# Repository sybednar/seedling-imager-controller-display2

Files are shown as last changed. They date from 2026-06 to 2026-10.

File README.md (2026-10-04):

# Seedling Imager Controller

## Overview
Inspired by the SPIRO (Smart Plate Imaging Robot; Ohlsson et al The Plant Journal doi: 10.1111/tpj.16587) project, the **Seedling Imager** is a Raspberry Pi 5-based imaging system designed to monitor Arabidopsis seedling growth using a 6-position hexagonal carousel. It provides automated imaging, LED control, and experiment scheduling through a touch-friendly GUI.

# Seedling Imager Controller — Universal

**v1.3.0** · Raspberry Pi 5 · PySide6 · picamera2 (or Arducam USB3) · GT2 belt carousel

A touchscreen controller for automated timelapse imaging of seedling plates using near-infrared (940 nm) transmission and front illumination. A single codebase runs on both supported display configurations without any code changes.

Repository: **https://github.com/sybednar/seedling-imager-controller-display2**

---

## Supported Hardware

| Component | System 1 (original) | System 2 |
|---|---|---|
| Display | Original 800×480 DSI touchscreen | Raspberry Pi Touch Display 2 (1280×720) |
| Scale factor `s` | 1.0 | 1.6 |
| Camera | Raspberry Pi HQ Camera | Raspberry Pi HQ Camera |
| Compute | Raspberry Pi 5 | Raspberry Pi 5 |
| Motor | Stepper + GT2 belt carousel | Stepper + GT2 belt carousel |
| Illumination | Dual 940 nm IR LEDs (front + rear) | Dual 940 nm IR LEDs (front + rear) |
| Optical sensor | Photointerrupter (hall + flag) | Photointerrupter (hall + flag) |
| Power (Pi 5) | SZZCNOX 5V/5A PD step-down module | SZZCNOX 5V/5A PD step-down module |

GUI layout, font sizes, button heights, and dialog dimensions all auto-scale via `s = screen_width / 800`. No separate display-specific files are needed.

> **Power supply note:** both systems use the same SZZCNOX 5V/5A USB-PD step-down board. A different-brand step-down module was tried on System 2 during a hardware upgrade and measured **5.42 V** on the Pi 5's 5V rail (GPIO pins 2/4) instead of 5.0 V — that ~0.2 V overvoltage is the confirmed cause of an intermittent shutdown/reboot hang (`plymouth-poweroff`/`plymouth-reboot` stuck for 1–2 minutes, or indefinitely). Swapping back to the SZZCNOX module resolved it completely. **Measure your 5V rail voltage before troubleshooting any shutdown/reboot instability in software** — it will look exactly like an OS or application bug otherwise. See Troubleshooting below.

---

## Key Features (v1.1.0)

### GUI & Display
- Auto-scaling dark theme UI: `s = screen_width / 800` (1.0 at 800 px, 1.6 at 1280 px)
- Fullscreen kiosk mode; all widget dimensions computed as `int(X * s)`
- `dark_style(s)` parameterized stylesheet — font, padding, and border-radius all scale

### Imaging
- Dual 940 nm IR illumination modes: **Front IR**, **Rear IR (transmission)**, **Combined**
- Per-mode camera presets stored in `camera_settings.json` (`FrontIR_*` / `RearIR_*` keys)
- Manual focus locked via `set_manual_focus()` at camera start (measured per unit — see Calibration Notes)
  - PDAF non-functional through 940 nm bandpass filter; manual focus required
- 16-bit grayscale TIFF output (`tifffile`; OpenCV fallback for non-TIFF formats)
- AE stability gate: polls `AnalogueGain` until < 5% relative change over 5 consecutive reads before pinning exposure
- `settling_started` signal emitted **after** AE is pinned and 0.20 s settle — GUI preview snapshot matches saved image exposure
- Live-view IR boost (mode-specific gain/exposure floor) enabled during preview, disabled before capture

### Motor / Carousel
- GT2 belt drive with dynamic bracket homing:
  1. CCW to LOW (leading edge of optical flag)
  2. CCW to HIGH (past leading edge)
  3. CW to LOW (re-validate leading edge)
  4. CW + `mid` µsteps to geometric center
- **Microstepping: 1/32** (BTT TMC2209: MS2=GND, MS1=VCC_IO). `steps_per_60_deg = 3200`.
  - This replaces the earlier 1/8-microstepping configuration (`steps_per_60_deg = 800`). 1/32 microstepping gives substantially finer positioning resolution and improved plate-to-plate registration — see Version History below.
  - **If you are upgrading an existing unit from a lower microstepping setting, delete `motion_cal.json` before the first run** — the saved calibration values do not scale automatically.
- Optical window `W` measured physically each homing run by counting µsteps CW across the sensor aperture (expected W ≈ 192 µsteps at 1/32 microstepping for the 5 mm stripe)
  - W is **not** a configurable parameter — it is measured live every homing cycle
- `CENTER_BACKOFF_FRAC = 0.0`: places carousel at exact geometric center regardless of W
  - Formula: `mid = max(1, int(round(W / 2.0 * (1.0 - CENTER_BACKOFF_FRAC))))`
  - Increase slightly (e.g. 0.05) only if consistent leading-edge drift is observed
- Log output includes `frac=` and `W=` on every homing for traceability

### Camera Backend (Picamera2 / Arducam USB3)
- Selectable in Camera Config → General tab: **Raspberry Pi Camera Module 3 (Picamera2)** [default] or **Arducam 20MP AR2020 Mono USB3**
- Persisted as `CameraBackend` in `camera_settings.json`; **switching requires an application restart** — the backend is fixed for the lifetime of the running process (`camera.py` only imports the selected backend module, since each one claims its physical camera device at import time)
- `camera.py` is a thin dispatcher: every other module calls `camera.get_frame()`, `camera.save_image()`, etc. unchanged regardless of which backend is active
- Arducam backend validated on physical hardware (Sept 2026): full-resolution reopen/discard/retry sequence confirmed reliable across extended multi-cycle experiments, including a `mock_capture()` path that exercises the same reopen sequence for unselected plates so every plate position gets a fresh, reliable on-screen preview whether or not it is actually captured that cycle. Before relying on it for a new unit:
  1. `sudo apt install v4l-utils` (already included in `install_dependencies.sh`)
  2. Connect the camera, then run `python3 -c "import camera_arducam_usb3 as c; c.print_diagnostics()"` — reports the detected `/dev/videoN` device, every resolution/format the driver advertises, and every V4L2 control it exposes
  3. Compare against the assumptions documented at the top of `camera_arducam_usb3.py` (control names, resolutions, mode-switch timing) and adjust the constants there if they don't match
- The Arducam is a **fixed physical manual-focus lens** (twist the M12 ring by hand) — there is no AF motor, so `set_manual_focus()`/AF-related calls are safe no-ops on this backend; the Focus tab in Camera Config has no effect when Arducam is selected
- UVC cameras generally stream one resolution at a time, unlike Picamera2's simultaneous main+lores streams — the Arducam backend runs live preview at a lower resolution continuously and briefly reconfigures to full resolution for each saved image (or each mock capture), so expect a short pause per cycle that the Picamera2 backend does not have

### Germination / Photomorphogenesis LEDs
- Independent on/off toggle buttons for **Blue (450 nm)**, **Red (660 nm)**, and **FarRed (730 nm)** — driven low-side via 3× IRLZ44N MOSFETs on the auxiliary MOSFET board
- Not coupled to the IR imaging illumination cycle — hold any combination on (e.g. Red+FarRed for a red:far-red ratio treatment) while IR imaging continues independently
- State is not persisted between sessions — all three channels default OFF at startup

### Camera Config Dialog
- Tabbed interface: General settings (incl. Camera Backend selector) + Focus + IR-specific presets
- "White LED Front" toggle button (GPIO23, persistent button row next to Apply/Close, not inside the Focus tab so it stays usable for either camera backend) — illuminates a Siemens star target during manual focus calibration; automatically turns off when the dialog closes (Close button, window X, or Escape key)
- Non-blocking "Read Current Position from Camera" button — `_FocusReader(QThread)` worker prevents GUI freeze when Live View is off
- Button disabled during read, re-enabled on completion or error

### Experiment Setup
- Configurable plate selection, frequency (default 30 min), duration, illumination mode
- Disk usage estimate uses `IMAGES_ROOT = Path("/home/sybednar/Seedling_Imager/images")` — **this path is hardcoded in `experiment_setup.py`.** If you use a different Linux username or folder layout, you must edit this line (see Setup, Step 0).
- Storage label colour: green (sufficient free space) / red (insufficient)

### File Manager
- Thumbnail grid with per-image metadata overlay
- Scaled thumbnail size: `QSize(int(100 * s), int(100 * s))`

---

## Module Structure

```
Seedling_Imager/                          # top-level project folder (NOT the git repo)
├── images/                               # timelapse output — IMAGES_ROOT (hardcoded path)
└── seedling_imager_controller/           # git clone of this repository
    ├── venv/                             # Python virtual environment (created locally, not in git)
    ├── main.py                           # Entry point; launches QApplication fullscreen
    ├── gui.py                            # Main window; computes s = screen_width / 800
    ├── styles.py                         # dark_style(s) — parameterized stylesheet
    ├── camera.py                         # Camera BACKEND DISPATCHER — selects picamera2 vs arducam_usb3
    ├── camera_picamera2.py               # Picamera2 backend; manual focus; TIFF save; AE gate
    ├── camera_arducam_usb3.py            # Arducam 20MP AR2020 mono USB3 backend (OpenCV/V4L2)
    ├── camera_config.py                  # Camera Config dialog; Camera Backend selector; _FocusReader QThread
    ├── motor_control.py                  # Stepper driver; dynamic bracket homing; 1/32 microstepping
    ├── experiment_runner.py              # Timelapse loop; AE settle; settling_started signal
    ├── experiment_setup.py               # Setup dialog; plate/frequency/mode/disk usage
    ├── file_manager.py                   # File browser with thumbnail grid
    ├── registration.py                   # Per-plate phase cross-correlation registration analysis
    ├── jog.py                            # Manual motor jog utility for bench testing
    ├── camera_settings.json              # Persisted camera presets (FrontIR_*, RearIR_* keys)
    ├── motion_cal.json                   # Persisted motor calibration (auto-created on first homing)
    ├── requirements.txt                  # pip dependencies (installed inside venv)
    ├── install_dependencies.sh           # One-shot apt + venv + pip installer
    ├── start_seedling_imager.sh          # Launch wrapper used by both autostart methods below
    ├── restart_seedling_imager.sh        # Manual stop/relaunch (used by desktop icon)
    ├── seedling-imager-autostart.desktop # XDG autostart template — RECOMMENDED (see Setup Step 8)
    ├── seedling-imager.service           # systemd --user service template — optional/alternative (see Setup Step 8)
    ├── Seedling_Imager.desktop           # Desktop icon template — start/restart the controller (see Setup Step 9)
    ├── git_update.sh                     # Convenience script for commit + tag + push
    ├── hardware/                         # CAD (STEP), KiCad boards, BOM, render, hardware licence — see hardware/README.md
    ├── logs/                             # Experiment run logs
    └── README.md
```

---

## GPIO Pin Map (as of v1.2.0)

All pins below are on the auxiliary MOSFET board or the motor driver, addressed via `gpiod` against `/dev/gpiochip0`.

| GPIO | Function | Module |
|---|---|---|
| 12 | Germination LED — Blue 450 nm | `gui.py` |
| 13 | Germination LED — Red 660 nm | `gui.py` |
| 16 | Motor DIR | `motor_control.py` |
| 17 | Front IR imaging panel (reflectance) | `gui.py` |
| 19 | Germination LED — FarRed 730 nm | `gui.py` |
| 20 | Motor STEP | `motor_control.py` |
| 21 | Motor driver EN | `motor_control.py` |
| 22 | Optical sensor (reflective stripe) | `motor_control.py` |
| 23 | Front panel White LED strip (Siemens star illumination during manual focus calibration) | `camera_config.py` |
| 24 | Green front illumination | `gui.py` |
| 26 | Hall sensor (motor pre-index) | `motor_control.py` |
| 27 | Rear IR imaging panel (transmission) | `gui.py` |

**v1.2.0 pin reshuffle:** `OPTICAL_PIN` moved 19→22 and the front/rear IR imaging panels moved 13→17 and 12→27, freeing GPIO12/13/19 for the three germination LED channels above. If you're carrying forward calibration or wiring notes from before v1.2.0, update them against this table, not the older pin numbers referenced in earlier Version History entries.

---

## Dependencies

Installed as **apt system packages** (compiled against Raspberry Pi OS's libcamera/Qt6/GPU libraries — do not pip-install these):
```
python3-picamera2
python3-pyside6.*    (no single "python3-pyside6" metapackage on current Raspberry Pi OS/Debian
                       Trixie — PySide6 is split per Qt module; the wildcard installs all of them:
                       sudo apt install 'python3-pyside6.*')
python3-numpy
python3-opencv      (cv2)
v4l-utils           (provides v4l2-ctl — only needed if using the Arducam USB3 camera backend)
libxcb-cursor0      (required by Qt >= 6.5's xcb platform plugin; usually already present, but
                     confirmed missing on at least one fresh Raspberry Pi OS Trixie image — see
                     Troubleshooting)
```

Installed as **pip packages inside the project virtual environment** (see `requirements.txt`):
```
tifffile   (16-bit TIFF read/write)
gpiod>=2.0 (stepper/LED GPIO — modern gpiod.line API; see https://pypi.org/project/gpiod/)
```

> **Note on GPIO library:** this project uses `gpiod` (the modern libgpiod v2.x Python bindings), **not** `RPi.GPIO` and **not** `gpiozero`. Both are absent from the codebase. `gpiod` is installed via pip (not apt) because the apt-packaged `python3-libgpiod` on current Raspberry Pi OS releases may ship an older 1.x API incompatible with `motor_control.py`'s `gpiod.line.Direction/Value/Bias` usage.

The `install_dependencies.sh` script (see Setup below) installs and verifies all of the above in one step.

---

## Setup — New Raspberry Pi 5 (Step by Step for Novices)

These instructions assume you have already flashed Raspberry Pi OS (Bookworm or Trixie) onto the NVMe/SD card, booted to the desktop, confirmed **Desktop Autologin** is enabled for your user (`sudo raspi-config` → System Options → Boot / Autologin → Desktop Autologin), and connected to Wi-Fi/Ethernet. All commands are run in a terminal on the Raspberry Pi itself (or over SSH — except where noted in Step 8/9, where a few things must be checked from a terminal running *inside* the desktop session itself).

### Step 0 — Confirm your Linux username

The code hardcodes the path `/home/sybednar/Seedling_Imager/...` in two places (`experiment_setup.py`'s `IMAGES_ROOT`, and the autostart scripts). Open a terminal and run:

```bash
whoami
```

- If it prints `sybednar`, continue to Step 1 as written.
- If it prints anything else, either (a) create a `sybednar` user on this Pi, or (b) do a project-wide find-and-replace of `/home/sybednar/` with `/home/<your-username>/` in `experiment_setup.py`, `start_seedling_imager.sh`, `restart_seedling_imager.sh`, `seedling-imager.service`, and `seedling-imager-autostart.desktop` before proceeding.

### Step 1 — Create the project folder

```bash
mkdir -p /home/sybednar/Seedling_Imager/images
cd /home/sybednar/Seedling_Imager
```

### Step 2 — Clone the repository

```bash
git clone https://github.com/sybednar/seedling-imager-controller-display2.git seedling_imager_controller
cd seedling_imager_controller
```

(HTTPS clone requires no GitHub account or SSH key setup — fine for read-only cloning of this public repo. If you need the Arducam USB3 branch specifically, add `-b arducam-integration` to the clone command.)

### Step 3 — Install dependencies (one command)

```bash
chmod +x install_dependencies.sh
./install_dependencies.sh
```

This installs the apt system packages, creates `venv/` with `--system-site-packages`, installs `requirements.txt` into it, and prints a verification check for every dependency (picamera2, PySide6, opencv, numpy, tifffile, gpiod). **Do not continue to Step 4 until this script finishes with no errors.**

### Step 4 — Make the launch/restart scripts executable

```bash
chmod +x start_seedling_imager.sh restart_seedling_imager.sh
```

### Step 5 — First manual run (before enabling autostart)

Always test manually first — it's much easier to read errors in a live terminal than in a log file. Run this from a terminal opened **on the Pi's own desktop** (not a bare SSH session), since the app needs the desktop's live display/session environment:

```bash
source venv/bin/activate
python3 main.py
```

The app should open fullscreen. Use Alt+F4 (or the on-screen Exit control, if present) to close it and return to the terminal. If it fails to start, see Troubleshooting below before continuing.

### Step 6 — Calibrate manual focus for this camera unit

Manual focus is **per-camera-unit** and must be re-measured on every new Pi/camera pairing — do not reuse another unit's value. Follow the steps in the repository's `Setting manual camera focus instructions` file, then update the `ManualFocusPosition` value(s) in `camera_settings.json`.

### Step 7 — Confirm the motor calibration file is fresh

If this SSD/OS image was ever used with a different microstepping setting or a different physical unit, delete the stale calibration before the first homing run:

```bash
rm -f /home/sybednar/Seedling_Imager/seedling_imager_controller/motion_cal.json
```

It will be recreated automatically the first time `home()` runs successfully from the GUI.

### Step 8 — Enable autostart (XDG autostart, recommended)

Two mechanisms exist for autostarting the controller GUI when the desktop session starts: a **systemd `--user` service** and an **XDG autostart `.desktop` entry**. Real-world testing across two different Pi 5 units (and, on one of them, two different OS images) consistently found the systemd method **unreliable for this application**: it works fine when started by hand in an already-running session (`systemctl --user enable --now ...`), but on a genuine cold `sudo reboot` it either fails with a Qt platform-plugin error or exits silently a few seconds after launch, with no window ever appearing. The confirmed root cause is that the systemd user manager on these Pi 5 / labwc images does not reliably import `XAUTHORITY`/`WLR_XWAYLAND` into its environment the way an interactive desktop session does — `DISPLAY` and `WAYLAND_DISPLAY` are present, but the xcb/XWayland platform plugin still can't authenticate without those two extra variables. `start_seedling_imager.sh` already sets explicit fallback defaults for both (see the script), which helps but has not made systemd fully reliable across every image tested. The **XDG autostart** method sidesteps the problem entirely, since the compositor launches it directly inside the already-fully-initialized session — it has been 100% reliable across every reboot/shutdown test performed. **Use it as the primary method:**

```bash
mkdir -p ~/.config/autostart
cp seedling-imager-autostart.desktop ~/.config/autostart/seedling-imager.desktop
```

**Reboot the Pi with `sudo reboot` (a real reboot — not `systemctl --user start`) and confirm the controller launches automatically to the fullscreen GUI.** Also test a full `sudo shutdown now` to confirm the Pi actually powers off cleanly. Testing only with a live-session start can look successful and still fail on a real cold boot — always validate with an actual reboot and an actual shutdown before considering autostart done.

If the GUI doesn't appear, check the log first:

```bash
tail -80 /home/sybednar/Seedling_Imager/seedling_imager_controller/autostart.log
```

<details>
<summary>Optional: systemd <code>--user</code> service (alternative method — click to expand)</summary>

If you'd prefer process supervision (automatic restart on crash) and are willing to validate it carefully, the systemd unit is still provided:

```bash
mkdir -p ~/.config/systemd/user
cp seedling-imager.service ~/.config/systemd/user/
systemctl --user daemon-reload
systemctl --user enable --now seedling-imager.service
```

Check it's running:

```bash
systemctl --user status seedling-imager.service --no-pager -l
```

**Do not stop here** — this only confirms it works when started inside your current live session, which is exactly the false-positive result seen on both test units before a real reboot exposed the failure. Reboot and re-check status/log before trusting it:

```bash
sudo reboot
# after it comes back up:
systemctl --user status seedling-imager.service --no-pager -l
tail -80 /home/sybednar/Seedling_Imager/seedling_imager_controller/autostart.log
```

If it fails (Qt platform-plugin error, or the log shows the script exiting cleanly within a few seconds of launch with no other error), fall back to the XDG method above:

```bash
systemctl --user disable --now seedling-imager.service
mkdir -p ~/.config/autostart
cp seedling-imager-autostart.desktop ~/.config/autostart/seedling-imager.desktop
sudo reboot
```

</details>

### Step 9 — Add the "Seedling Imager" desktop icon

This lets you start (or stop-and-relaunch) the controller from the touchscreen — e.g. after using "Exit to Desktop" to review files — without rebooting the Pi.

```bash
cp Seedling_Imager.desktop ~/Desktop/
chmod +x ~/Desktop/Seedling_Imager.desktop
```

**Two one-time desktop settings, or the icon won't work smoothly:**

1. On first double-click, the file manager may show an "Untrusted application launcher" warning — right-click the icon and choose **Allow Launching** (or **Trust**), then it will run normally from then on.
2. By default, clicking an executable `.desktop`/script icon pops up an "Execute / Execute in Terminal / Display / Cancel" dialog every time instead of just running it. To disable this: open the **File Manager**, go to **Edit → Preferences** (or right-click the desktop → **Desktop Preferences**, depending on OS version), find the **General** tab, and check **"Don't ask options on launch executable file."** Without this, every click on the icon interrupts the user with an extra dialog.

The icon uses `seedlings.png` (already in this repo) and calls `restart_seedling_imager.sh`, which kills any already-running instance of the GUI and relaunches `start_seedling_imager.sh` fresh — safe to click whether or not the controller is currently running.

### Step 10 — Run a short registration test

Run a short multi-cycle experiment (a few plates, a few cycles) and inspect results with `registration.py` to confirm the 1/32-microstepping `motor_control.py` gives the same registration improvement seen on System 1 before starting a long unattended run.

---

## Troubleshooting

| Symptom | Likely cause / fix |
|---|---|
| `pip install` fails with "externally-managed-environment" | You're not inside the venv, or the venv was created without `--system-site-packages`. Re-run `source venv/bin/activate` first, or rebuild the venv per Step 3. |
| `ModuleNotFoundError: No module named 'picamera2'` inside the venv | The venv wasn't created with `--system-site-packages`, or the apt package `python3-picamera2` isn't installed. Rebuild: `rm -rf venv && python3 -m venv --system-site-packages venv`, then re-run `install_dependencies.sh`. |
| `ImportError: cannot import name 'Direction' from 'gpiod.line'` | An old `gpiod` (1.x) is shadowing the pip-installed 2.x version. Confirm with `venv/bin/pip show gpiod` (should be ≥2.0) and re-run `venv/bin/pip install --upgrade gpiod`. |
| `qt.qpa.plugin: Could not load the Qt platform plugin "xcb" ... xcb-cursor0 or libxcb-cursor0 is needed` | Missing system library required by Qt ≥ 6.5. Fix: `sudo apt-get install -y libxcb-cursor0`. Seen on a fresh Raspberry Pi OS Trixie image where it wasn't pulled in automatically. |
| `qt.qpa.xcb: could not connect to display` when testing manually | You're running the command over plain SSH (no `DISPLAY`), not in a terminal inside the desktop session. Either open a terminal locally on the Pi's touchscreen, or (for a quick manual check only) `export DISPLAY=:0` in the SSH shell first. |
| GUI never appears at boot, but manual `python3 main.py` (run inside the desktop session) works fine | This is the systemd `XAUTHORITY`/`WLR_XWAYLAND` gap described in Setup Step 8. Switch to the XDG autostart method — don't spend time tuning `QT_QPA_PLATFORM` or startup delay first, since neither addresses the actual cause. |
| systemd service shows `enabled`, `autostart.log` shows the script reach `Seedling Imager launch end` a few seconds after launch, but no window ever appeared | The app started and exited cleanly on its own under systemd — a different, not-fully-understood failure mode from the Qt platform-plugin error above, also resolved by switching to XDG autostart. Confirmed independent of camera backend and hardware revision. |
| systemd service works when started by hand (`enable --now`) but not after a real `sudo reboot` | Expected — see Setup Step 8. Validate autostart only with a genuine reboot, never with a live-session start. |
| `sudo shutdown`/`sudo reboot` hangs for 1–2 minutes (or indefinitely) at a `plymouth-poweroff`/`plymouth-reboot` message | Check your Pi 5's 5V rail voltage (GPIO pins 2/4) before assuming it's a software issue — a step-down power module running even slightly over 5.0 V (5.4 V confirmed to cause this) can produce exactly this symptom. See the Power Supply note near the top of this README. Also run `sudo rpi-eeprom-update` and apply any pending bootloader update (`sudo rpi-eeprom-update -a && sudo reboot`) as a secondary check, especially on units with an NVMe HAT. A momentary pushbutton wired to the J2 GPIO shutdown pins will reliably force a clean power-down while you diagnose this. |
| Clicking the desktop icon pops up an Execute/Terminal/Cancel dialog every time | See Setup Step 9 — enable "Don't ask options on launch executable file" in the File Manager's preferences. |
| Homing/centering seems off after this update | Delete `motion_cal.json` and re-home — old calibration values from a different microstepping setting do not carry over (see Motor / Carousel notes above). |

---

## Migrating an Existing Unit to This Layout

If a unit's folder/autostart layout predates this document, bringing it in line is usually a small job, not a rebuild:

1. **Confirm the folder structure first before assuming anything needs to move.** Check `ls -la /home/<user>/Seedling_Imager/` and `ls -la /home/<user>/Seedling_Imager/seedling_imager_controller/venv/bin/python3` — many units already have the correct layout (repo cloned into `Seedling_Imager/seedling_imager_controller/`, venv nested inside it) even if that wasn't true at some earlier point in the unit's history. Don't move files that are already in the right place.
2. **The autostart mechanism is the part most likely to need changing.** If the unit currently relies on the systemd `--user` service, convert it to the XDG autostart method per Setup Step 8 — do this even if the systemd version currently "seems to work," since a live-session start can pass while a real cold reboot fails (see Troubleshooting). Validate with an actual `sudo reboot` and `sudo shutdown`, not just `systemctl --user enable --now`.
3. Update the desktop icon to the current `Seedling_Imager.desktop` template and confirm the File Manager preference from Setup Step 9 is set.
4. Back up (rename, don't delete) any old/stale project folders before removing them, and only delete the backups once the converted unit has been confirmed working across a real reboot and shutdown.
5. **Do not touch a unit while it is running an experiment.** Do this migration between experimental runs.

---

## Calibration Notes

### Manual Focus
- Manual focus is per-camera-unit. Measure and set `ManualFocusPosition` in `camera_settings.json` for each new system — do not copy another system's value.
- PDAF is non-functional through the 940 nm bandpass filter on both systems.

### Optical Window W
W is measured automatically on every homing cycle — no manual configuration needed. Expect W ≈ 192 µsteps at 1/32 microstepping for the 5 mm stripe.

### CENTER_BACKOFF_FRAC
At the top of `motor_control.py`. Default `0.0` places the carousel at exact geometric window center. Only increase if consistent leading-edge drift is observed in registration analysis.

---

## Hardware Design Files

The complete open-source hardware design is in [`hardware/`](hardware/README.md): the full assembly and individual parts in STEP format, KiCad 10 schematics and PCB layouts for the controller boards and hall sensor board, and a bill of materials (`hardware/CAD Files/bill_of_materials.md`). The native Fusion archive (`.f3z`) and full-assembly STEP are too large for the repository and are attached to the [latest GitHub Release](https://github.com/sybednar/seedling-imager-controller-display2/releases/latest). Hardware files are licensed under CERN-OHL-S v2; the software is MIT.

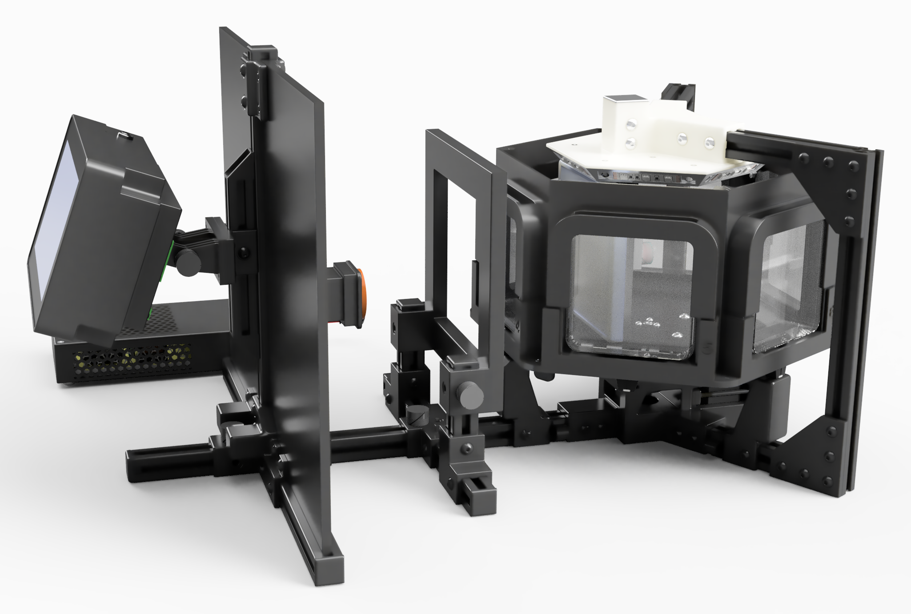
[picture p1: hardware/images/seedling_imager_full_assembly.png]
Seedling imager full assembly render


---

## Version History

### v1.3.2 — 2026-10-04 — Hardware documentation and naming corrections

- Renamed the IR filter holder component to "850 nm long-pass filter holder" in the CAD (Fusion archive and all STEP files)
- Clarified that the camera housing, filter holder and rail corner bracket are included in the Picamera mount STEP; updated root README, CHANGELOG and citation
- Software unchanged from v1.3.0

### v1.3.1 — 2026-10-04 — Complete hardware design files

- Added the complete hardware design (`hardware/`): full-assembly STEP (zipped) and individual part STEP files by subsystem, KiCad 10 files for controller board 1, board 2 and the hall sensor board, bill of materials, assembly render, and CERN-OHL-S v2 licence/notice
- Fusion archive (`.f3z`) and full-assembly STEP attached to the GitHub Release (files exceed GitHub's 100 MB repository limit)
- Added root `LICENSE` (MIT) for the software
- Software unchanged from v1.3.0

### v1.3.0 — 2026-09-27 — Arducam reliability fixes, White LED Front control, Picamera2 for production

**Reliability fixes**
- Fixed `focus_tune.py` sharpness score: removed per-frame min/max contrast normalization that was causing the reported score to rise with *increasing* defocus instead of decreasing
- Fixed Arducam USB3 single-capture failure (root-caused via `dmesg`: `uvcvideo: Failed to resubmit video URB`, a genuine kernel-level USB/firmware wedge triggered by rapid full-res/preview mode switching) — added a settle delay before reopening the device plus self-healing device re-detection (`_find_device(force_refresh=True)`)

**New hardware control**
- Added a "White LED Front" toggle button (GPIO23) to the Camera Config dialog, placed in the persistent button row so it stays usable regardless of active tab or selected backend. Illuminates a Siemens star target for manual focus calibration on either camera; auto-shuts-off via the dialog's `finished` signal so it turns off no matter how the dialog is closed
- Corrected GPIO Pin Map: GPIO23 and GPIO24 were previously documented as "reserved, not yet implemented" — GPIO24 was already driving the Green front illumination LED (`gui.py`), and GPIO23 now drives the White LED Front strip above, both via the AO4805 MOSFET auxiliary board

**Hardware/production decision**
- Head-to-head image-quality comparison on both systems (focus, depth of field, sharpness) showed Picamera2/Camera Module 3 substantially outperforming the Arducam 20MP AR2020 Mono + AICO M12 lens combination for real seedling-plate imaging, after root-causing the Arducam's low sharpness ceiling to a Minimum-Object-Distance violation (measured working distance below the lens's MOD). Both systems switched to Picamera2 for production experiments; the Arducam lens/working-distance problem is tabled for future revisit — the backend and its fixes above remain in the codebase and selectable via Camera Config

**Repo maintenance**
- Consolidated system 1 onto `origin/main`, resolving stale branch/merge-conflict history
- Fixed GitHub default branch (was pointing to the archived `archive-pre-arducam-2026-04` branch instead of `main`); deleted stale `arducam-integration` and `archive-pre-arducam-2026-04` branches and the leftover local `main-old-stale`

### v1.2.1 — 2026-09 — Autostart reliability fix + setup documentation overhaul

**Autostart**
- Root-caused systemd `--user` autostart unreliability to `XAUTHORITY`/`WLR_XWAYLAND` not being reliably imported into the systemd user manager's environment on Pi 5/labwc images, even though `DISPLAY`/`WAYLAND_DISPLAY` are present. `start_seedling_imager.sh` now sets explicit fallback defaults for both.
- XDG autostart (`~/.config/autostart/`) promoted to the **recommended** primary method after passing repeated real cold-reboot and full-shutdown testing on two separate physical units; systemd retained as a documented, secondary/optional method.
- Desktop icon renamed/consolidated to a single `Seedling_Imager.desktop` template (start-or-restart), replacing the earlier restart-only icon naming.

**Hardware**
- Documented a confirmed root cause for intermittent `plymouth-poweroff`/`plymouth-reboot` shutdown hangs: a non-matching 5V step-down power module running at 5.42 V instead of 5.0 V. Resolved by standardizing on the SZZCNOX 5V/5A module on both systems.
- Added `sudo rpi-eeprom-update` as a secondary shutdown-instability check, particularly for units with an NVMe HAT.

**Camera**
- Arducam USB3 backend validated against physical hardware across extended multi-cycle runs; added `mock_capture()` so every plate position gets a fresh, reliable on-screen preview regardless of whether that plate is actually captured that cycle.

**Dependencies**
- Added `libxcb-cursor0` as a documented apt dependency (Qt ≥ 6.5 requirement, found missing on a fresh Raspberry Pi OS Trixie image).

### v1.2.0 — 2026-08 — Selectable camera backend, germination LEDs, GPIO reshuffle

**Camera**
- `camera.py` split into a backend dispatcher plus two implementations: `camera_picamera2.py` (existing Picamera2/libcamera code, behavior unchanged) and new `camera_arducam_usb3.py` (OpenCV/V4L2 backend for the Arducam 20MP AR2020 monochrome USB3 camera)
- Backend selectable in Camera Config → General (`CameraBackend` in `camera_settings.json`); requires an app restart to take effect

**Hardware / GPIO**
- Added a 3-channel germination/photomorphogenesis LED strip (Blue 450 nm, Red 660 nm, FarRed 730 nm) with independent GUI on/off toggles, driven low-side via IRLZ44N MOSFETs on a new auxiliary MOSFET board
- Reshuffled GPIO pins to make room: `motor_control.py`'s `OPTICAL_PIN` moved 19→22; `gui.py`'s front/rear IR imaging panel pins moved 13→17 and 12→27. See the GPIO Pin Map above for the full current assignment, including GPIO23/24 reserved for a planned rear-IR940 PWM intensity control (AO4805 mosfet, not yet implemented in software)

**Dependencies**
- Added `v4l-utils` (apt) for the Arducam backend's `v4l2-ctl`-based exposure/gain control

### v1.1.0 — 2026-07 — 1/32 microstepping + documentation overhaul

**Motor**
- `motor_control.py` updated from 1/8 to 1/32 microstepping (`steps_per_60_deg`: 800 → 3200), same single-optical-sensor + 6-stripe dynamic-bracket strategy. Finer step resolution further improves plate-to-plate registration.
- Cleaned a leftover dead-code block in `_debounced_read()`.

**Documentation**
- Corrected GPIO dependency: `RPi.GPIO`/`gpiozero` (never used in code) replaced with `gpiod>=2.0` throughout.
- Replaced three conflicting clone/folder-structure instructions with a single canonical layout and step-by-step novice setup guide.
- Added `requirements.txt`, `install_dependencies.sh`, systemd service template, XDG autostart fallback template, and desktop restart-icon template — previously undocumented/uncommitted.
- Fixed repository URL (previous README referenced two nonexistent repo names).

### v1.0.0 — 2026-04-22 — Universal release

**Architecture**
- Single codebase runs on both 800×480 and 1280×720 displays without modification
- `s = screen_width / 800` computed once in `gui.py`; every pixel dimension expressed as `int(X * s)`
- `dark_style(s)` replaces fixed stylesheet string; font, padding, border-radius all scale with `s`

**Motor / centering fix**
- `CENTER_BACKOFF_FRAC = 0.0` replaces fixed `CENTER_BACKOFF = 5`
- Fixes System 1 centering error: with W=12 the old formula gave `mid=1` (leading edge) instead of `mid=6` (center)
- After pulley realignment: W=23–24, mid=12; registration RMS improved ~79% (6.7 px → 1.4 px mean)

**Imaging**
- AE stability gate: waits for AnalogueGain < 5% relative change × 5 consecutive reads before pinning exposure
- `settling_started` signal timing fixed: now emitted after AE pin + 0.20 s settle, not before — preview snapshot matches saved image exposure
- Non-blocking Read Focus button: `_FocusReader(QThread)` prevents GUI freeze when Live View is off

**Bug fixes**
- `IMAGES_ROOT` constant added to `experiment_setup.py` (was causing silent disk estimate failure)
- Experiment frequency default restored to 30 minutes
- `apply_main_illum_style` scope fix: `s = self._s` added inside method body
- `experiment_setup.py` line 235: orphaned `else` clause fixed (comment had been inserted between `if` body and `else`)
- `gui.py`: `setStyleSheet(dark_style(s))` moved to after `s` is computed (was causing `UnboundLocalError`)

**All v0.06 Display2 features carried forward**
- Dual 940 nm IR illumination (front + rear), per-mode camera presets
- Tabbed Camera Config dialog, File Manager with thumbnails, CSV metadata
- GT2 belt drive, autostart and desktop launcher

### v0.06 — Display2-specific release
Dual-stream camera, TIFF output, autofocus, File Manager with thumbnails, CSV metadata, Camera Config dialog, autostart and desktop launcher, GT2 belt drive initial implementation, per-mode IR presets.

---

## Registration Performance (System 1, v1.0.0, 1/8 microstepping baseline)

Rear IR transmission, 8 cycles, plates 1 and 2:

| Metric | v0.06 baseline | v1.0.0 |
|---|---|---|
| Mean RMS | 6.7 px | 1.4 px |
| Mean \|dx\| | 6.5 px | 1.3 px |
| dx bias | +6.5 px (systematic) | −0.4 px (eliminated) |
| Cycles at 0 px shift | 0 of 4 | 9 of 14 (64%) |
| Max \|dx\| | 10 px | 6 px |

Residual jitter (2–6 px) is intrinsic GT2 belt backlash and stepper microstepping nonlinearity. Software registration using ArUco or QR fiducial markers on plate backs can correct remaining shift to sub-pixel if required for quantitative analysis. **1/32-microstepping results from System 2 will be added here once validated (see Setup Step 10).**

---

## License

Software: MIT — see `LICENSE` file. Hardware design files (`hardware/`): CERN-OHL-S v2 — see `hardware/LICENSE-CERN-OHL-S-v2.txt`.

Citation: Bednarek, S. Y., Yong, C. W. J., Hoey, E. A. and Murua, K. (2026). *seedling-imager-controller-display2* (v1.3.2). Zenodo. https://doi.org/10.5281/zenodo.23144486 (all versions: https://doi.org/10.5281/zenodo.20738657).

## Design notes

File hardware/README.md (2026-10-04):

# Seedling Imager — Hardware Design Files

Render of the complete seedling imager assembly

Open-source hardware for an automated, six-plate time-lapse seedling imaging robot.
This folder contains the mechanical CAD files, controller electronics (KiCad), bill of
materials, and licensing for the imager; the Raspberry Pi controller and
image-acquisition/registration software live in the root of this repository.

## Overview

The instrument is a rotating hexagonal carousel that holds up to six Petri plates and
presents each in turn to a fixed high-resolution camera. It is controlled by a
Raspberry Pi with a stepper motor and optical/magnetic position sensors, so every plate
returns to the same imaging position on each cycle. Plates are illuminated with both
transmitted and reflected 940 nm infrared light, allowing seedlings to be grown and
imaged either in the light or in complete darkness (etiolated), typically at 1–2 hour
intervals over 5–7 days. The system captures 16-bit grayscale TIFF images and
automatically aligns successive frames of each plate by phase cross-correlation
(frame-to-frame registration to ~2 pixels in current data).

The design was inspired by the open-source SPIRO Petri-plate imaging robot
(Ohlsson et al., 2024, *The Plant Journal* 118:584–600) and extends it with greater
plate capacity, dual transmitted + reflected IR illumination, and improved registration
reproducibility for quantitative time-lapse growth analysis.

## Contents

| Path | Description |
|---|---|
| `seedling imager_full assembly.step.zip` | Complete assembly in neutral STEP format (zipped; unzip before opening). Opens in any CAD package (FreeCAD, SolidWorks, Onshape, etc.). |
| Fusion archive `seedling imager_full assembly.f3z` | Native Autodesk Fusion archive of the complete assembly (127 MB, too large for the repository). Download from the **[latest GitHub Release](https://github.com/sybednar/seedling-imager-controller-display2/releases/latest)** and open in Fusion. |
| `CAD Files/` | Individual part and sub-assembly STEP files, organized by subsystem (below), plus `bill_of_materials.md`. |
| `Electronics/` | KiCad 10 schematic and PCB design files for the controller boards and hall sensor board (below). |
| `LICENSE-CERN-OHL-S-v2.txt` | Hardware license (see Licensing). |
| `NOTICE.txt` | Required CERN-OHL-S copyright/license notice. |

### CAD Files/ (STEP format, by subsystem)

| Folder | Contents |
|---|---|
| `Drive Base and Frame/` | Base plate, top plate, motor tensioning plate |
| `Carousel Assembly/` | Six-plate carousel with dual-bearing belt drive, carousel support bracket, adjustable bearing arms (including the optical sensor mount and the hall sensor arm), acrylic plate diffuser, the dual bearing belt drive motor base block, and the magnet and optical carousel position sensor triggers |
| `Rear Illuminator/` | Rear IR/illumination support hub |
| `Camera and Controller Mount/` | Display/camera rail light screen mounting hub assembly; Picamera mount with CSI-to-HDMI board (includes the camera housing, IR long-pass filter holder and rail corner bracket) |
| `Controller Enclosure/` | Display/touchscreen controller enclosure assembly (hinge, touchscreen compartment, RPi compartment, rear panel) |
| `Controller Subassembly/` | 3D models of the custom controller boards (Seedling Imager board_1 and board_2) |
| `Miscellaneous Hardware/` | 2020 T-slot end cap with cover, 2020 T-slot cover wire guide, 2020 8 mm cable guide, 100 mm × 15 mm square Petri dish magnetic fastener (8 mm magnet), M5 thumb screws (15 mm and 25 mm), Meanwell LRS-100-12 power supply enclosure, corner bracket, and fabrication jigs (acrylic diffuser hole-drilling jig, spindle heat-set insert installation jig) |

Standard off-the-shelf hardware (fasteners, 2020 aluminum extrusion, stepper motor, etc.)
is not included as CAD files — see `CAD Files/bill_of_materials.md` for part numbers.

### Electronics/ (KiCad 10)

| Folder | Description |
|---|---|
| `Seedling Imager board_1/` | Main controller board (TMC2209 stepper driver, LED and sensor interfaces). Includes the `TSW_103_07_L_S` library (symbol, footprint and 3D model for the 0.1" pitch header). |
| `Seedling Imager board_2/` | Auxiliary MOSFET board for LED illumination control. |
| `Seedling Imager hall sensor board/` | A3144 hall sensor board mounted in the adjustable bearing arm for magnetic carousel position sensing. |

Each folder holds the `.kicad_pro`, `.kicad_sch` and `.kicad_pcb` files; open the
`.kicad_pro` in KiCad 10 or later. Schematic symbols and PCB footprints are embedded in
the files, so the boards open without extra libraries. Some PCB files reference 3D
models by absolute path on the author's machine; these only affect the 3D viewer and can
be re-pointed in *PCB Editor ▸ Preferences ▸ Configure Paths* or by editing footprint
properties.

## Opening the design files

- **STEP (.step):** Unzip `seedling imager_full assembly.step.zip`, then open the `.step`
  in any CAD program. STEP preserves exact solid geometry and is the recommended
  starting point for reuse or modification outside Fusion. The individual `.step` files
  in `CAD Files/` can be opened directly.
- **Fusion archive (.f3z):** Download it from the latest GitHub Release, then in Autodesk Fusion use *File ▸ Open* and select the `.f3z`,
  or upload it to your Fusion data panel. This is the fully editable source design
  (Fusion is free for personal/hobbyist use).

## Bill of materials

See `CAD Files/bill_of_materials.md`, grouped by category (structural and motion
components, electronics, power, motor, lights, wiring, hardware, ArUco markers, 2020
extrusion cut list, camera housing hardware, and controller board connectors).

## Notes

- An alternate camera/lens configuration (Arducam 20 MP monochrome + Computar M0814-MP2
  C-mount lens) was evaluated but has not yet been built or tested. Its CAD files are not
  included; the Picamera system above is the one running production experiments.
- The camera housing/mount, the IR long-pass filter holder (for the 37 mm 850 nm filter) and the
  mounting rail corner bracket are modeled as components of
  `Camera and Controller Mount/picamera mount_with csi to hdmi board.step` (and of the full
  assembly) rather than as separate files.

## Build and operation

Controller setup, camera configuration, and operation: see the documentation in the
repository root (`README.md`, `Camera configuration_user guide`,
`Setting manual camera focus instructions`).

## Licensing

This project uses two licenses:

- **Hardware design files** (CAD, STEP, KiCad, BOM) in this folder are licensed under the
  **CERN Open Hardware Licence Version 2 — Strongly Reciprocal (CERN-OHL-S v2)**.
  See `LICENSE-CERN-OHL-S-v2.txt` and `NOTICE.txt`.
- **Software** (the Raspberry Pi controller and image-acquisition/registration code) in
  the repository root is licensed under the **MIT** license.
  See the `LICENSE` file at the repository root.

## Citation

If you use this hardware or software, please cite the archived release:

> Bednarek, S. Y., Yong, C. W. J., Hoey, E. A. and Murua, K. (2026). *seedling-imager-controller-display2: control and image-acquisition
> software and hardware design files for an open-source six-plate infrared seedling imaging
> robot* (v1.3.2) [Software and hardware design files]. Zenodo. https://doi.org/10.5281/zenodo.23144486
>
> The DOI above is for release v1.3.2. To cite all versions (always resolves to the latest
> release), use https://doi.org/10.5281/zenodo.20738657.

## Contact

Sebastian Y. Bednarek, University of Wisconsin–Madison — sybednar@wisc.edu

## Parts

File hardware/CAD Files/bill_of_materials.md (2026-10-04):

# Bill of Materials — Seedling Imager (Picamera System)

Off-the-shelf parts, electronics, hardware, and consumables used to build the seedling imager. This is an in-progress, working draft maintained by the project author (Sebastian Bednarek) — quantities, sources, and prices should be verified before ordering. Standard McMaster-Carr fasteners also appear in the per-subsystem notes elsewhere in this repo; this file is the authoritative, more complete list.

## General, Structural & Motion Components

| Qty | Description | Price | Source / Part No. |
|---|---|---|---|
| 1 | FLASHFORGE PETG Pro Filament 1.75mm Black, 3D Printer Filament 1kg | $17.59 | https://www.amazon.com/dp/B07Y9S22P5?ref=ppx_yo2ov_dt_b_fed_asin_title&th=1 |
|  | FLASHFORGE PETG Pro Filament 1.75mm White, 3D Printer Filament 1kg | $17.59 | https://www.amazon.com/dp/B07Y9T8HLX?ref=ppx_yo2ov_dt_b_fed_asin_title&th=1 |
|  | FLASHFORGE Rapid PETG Filament 1.75mm Clear | $17.59 | [link](https://www.amazon.com/FLASHFORGE-Filament-Printing-Dimensional-Accuracy/dp/B0FMYDB2TF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) |
| 1 | 4pcs 500mm T Slot 2020 Aluminum Extrusion |  | https://www.amazon.com/dp/B08Y8KCJW4?ref=ppx_yo2ov_dt_b_fed_asin_title&th=1 |
| 1 | 50Pcs M5 Spring T Nut 2020 Aluminum Extrusion T Nuts |  | https://www.amazon.com/dp/B09H5BK21X?ref=ppx_yo2ov_dt_b_fed_asin_title&th=1 |
| 1 | daier 2Pcs 8mm Aluminium Alloy Flange Coupling Connector |  | https://www.amazon.com/dp/B0CJMG1QQH?ref=ppx_yo2ov_dt_b_fed_asin_title&th=1 |
|  | 2-Pack 8mm x 150mm Linear Motion Rods Shaft Guide for 3D Printer |  | https://www.amazon.com/dp/B0BNL57QGL?ref=ppx_yo2ov_dt_b_fed_asin_title&th=1 |
|  | PGN (10 Pack) 608-2RS Bearing - Lubricated Chrome Steel Sealed Ball Bearing |  | https://www.amazon.com/dp/B07XVPGMXQ?ref=ppx_yo2ov_dt_b_fed_asin_title&th=1 |
| 1 | uxcell 635-2RS Deep Groove Ball Bearing 5x19x6mm Double Sealed ABEC-3 Bearings 10-Pack |  | https://www.amazon.com/dp/B07T1BQXWJ?ref=ppx_yo2ov_dt_b_fed_asin_title&th=1 |
| 1 | STEPPERONLINE Nema 17 Stepper Motor Bipolar 2A 59Ncm(84oz.in) 48mm Body 4-Lead |  | https://www.amazon.com/dp/B00PNEQKC0?ref=ppx_yo2ov_dt_b_fed_asin_title |
| 1 | uxcell 6805-2RS Deep Groove Ball Bearings 25mm Inner Dia 37mm OD 7mm Bore Double Sealed Chrome Steel Z2 5pcs | $9.69 | https://www.amazon.com/dp/B082PWQNJB?ref_=ppx_hzsearch_conn_dt_b_fed_asin_title_2&th=1 |
| 1 | uxcell 635-2RS Deep Groove Ball Bearing 5x19x6mm Double Sealed ABEC-3 Bearings 10-Pack | $9.89 | https://www.amazon.com/dp/B07T1BQXWJ?ref_=ppx_hzsearch_conn_dt_b_fed_asin_title_6&th=1 |
| 1 | Saiper GT2 20 Teeth 5mm Bore Timing Pulley Aluminum Synchronous Wheel for 6mm Belt, (5pcs) | $6.99 | https://www.amazon.com/dp/B07MN2C5WJ?ref_=ppx_hzsearch_conn_dt_b_fed_asin_title_3&th=1 |

## Electronics

| Qty | Description | Price | Source / Part No. |
|---|---|---|---|
| 1 | Pololu 5V, 9A Step-Down Voltage Regulator D24V90F5 |  | https://www.pololu.com/product/2866/pictures |
|  | SZZCNOX 5V5A PD Power Expansion Board for Raspberry Pi 5, Power Converter Expansion Board 12V to 5V Step-Down Power Supply | $21.48 | https://www.amazon.com/dp/B0F5BFJ3LJ?ref=ppx_yo2ov_dt_b_fed_asin_title&th=1 |
| 1 | raspberry pi 5 4GB |  | [link](https://www.adafruit.com/product/5812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) |
| 1 | raspberry pi 5 active cooler |  | https://www.adafruit.com/product/5815 |
| 1 | NVME  512Gb SSD drive (2280 size) |  | [link](https://www.amazon.com/Silicon-Power-512GB-Gen3x4-SP512GBP34A60M28/dp/B07ZGJYLNL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) |
|  | NVMe Base for Raspberry Pi 5 | $18.03 | [link](https://shop.pimoroni.com/products/nvme-base?variant=41219587211347 or https://www.adafruit.com/product/5845?srsltid=AfmBOordsLXaGGywxHh50zZY9lF5u67oRHsDvl5mIHz32KIYHbFcq059) |
|  | Raspberry pi Touch Display 2 | $108.49 | https://www.amazon.com/dp/B0DM24QFCF?ref=ppx_yo2ov_dt_b_fed_asin_title |
| 1 | raspberry pi camera 3 module |  | https://www.adafruit.com/product/5659 |
| 1 | Miniature Reflective Infrared Optical Sensors - 5 Pack - ITR20001/T |  | https://www.adafruit.com/product/3930 |
|  | A3144 3 Terminal Sensitive Hall Effect Switch Sensor 10 per pack |  | https://www.amazon.com/dp/B00SWK15ZE?lv=shuf&channelId=500&plpRedirect=mhFallback |
|  | Arducam CSI to HDMI Cable Extension Module with 15pin 60mm FPC Cable for Raspberry Pi Camera V3/V1/V2/HQ |  | https://www.amazon.com/dp/B06XDNBM63?ref=ppx_yo2ov_dt_b_fed_asin_title&th=1 |
|  | CONN JACK PNL MNT 5.5X2.1MM ISO  power barrel connector jack or use cable and jack assembly (below) | $4.81 | [link](https://www.digikey.com/en/products/detail/tensility-international-corp/54-00151/9829987  Digikey 839-54-00151-ND) |
|  | Power jack cable assembly Tensility  10-03609  Cable Assembly 2.1mm ID, 5.5mm OD Jack to Wire Leads Flat 1.00' (305.00mm) |  | digikey 839-10-03609-ND |
|  | Cable Assembly 2.1mm ID, 5.5mm OD Plug, Right Angle to Wire Leads Flat 6.0' (1.83m) Tensility |  | digikey  839-10-01780-ND 839-10-01780-ND |
|  | 8mm Switch:Momentary Toggle Push Button Switch |  | https://www.amazon.com/dp/B0CXSF5HLG?ref=ppx_yo2ov_dt_b_fed_asin_title&th=1 |
|  | MOLEX PICO BLADE 2-PIN CABLE - 2 |  | digikey 1528-2732-ND |

## Power supply

| Qty | Description | Price | Source / Part No. |
|---|---|---|---|
|  | Meanwell LRS-100-12 Enclosed AC DC Converters 1 Output 12V 85 ~ 264 VAC Input |  | digikey 1866-3312-ND |
|  | TE Connectivity Power Entry Connector Receptacle 6ESRM-3, Male Blades IEC 320-C14 Panel Mount, Flange |  | digikey CCM1401-ND |
|  | E-Switch RA1113112R Rocker Switch SPST 10A (AC) 125 V Panel Mount, Snap-In |  | digikey EG5619-ND |
|  | Essentra Components CG-PG7-BK CABLE GLAND 2-5MM PG7 POLYAMIDE |  | digikey 1866-3312-ND |
|  | Essentra Components PG7 Locknut Nut 0.748" (19.00mm) Nylon |  | digikey RPC3640-ND |

## Motor

| Qty | Description | Price | Source / Part No. |
|---|---|---|---|
|  | STEPPERONLINE Nema 17 Stepper Motor Bipolar 2A 59Ncm(84oz.in) 48mm Body |  | https://www.amazon.com/dp/B00PNEQKC0?ref_=ppx_hzsearch_conn_dt_b_fed_asin_title_5&th=1 |
|  | BIGTREETECH TMC2209 V1.3 UART Stepper Motor Driver 2.8A Peak Stepstick Silent Driver |  | https://www.amazon.com/dp/B08SMDY3SQ?ref_=ppx_hzsearch_conn_dt_b_fed_asin_title_4&th=1 |

## Lights

| Qty | Description | Price | Source / Part No. |
|---|---|---|---|
|  | 940nm SMD2835 DC12V Infrared LED Strip Light – Invisible IR for Cameras & Sensors, 120 LEDs/m, 5 Meters, non waterproof |  | [link](https://www.ledlightsworld.com/products/940nm-smd2835-dc12v-infrared-led-strip-light-invisible-ir-for-cameras-sensors-60-120-240-leds-m-5-meters-ip00-ip65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) |
|  | 12V-SB-GRN-12M 517 nm green 18 leds/ft |  | https://www.digikey.com/en/products/detail/inspired-led-llc/12V-SB-GRN-12M/5866479 |
|  | 450nm + 660nm + 730nm Tri-Spectrum Tunable Red Blue LED Horticulture Grow Light Strip |  | [link](https://www.superlightingled.com/450nm-660nm-730nm-trispectrum-tunable-red-blue-led-horticulture-grow-light-strip-p-7120.html) |

## Wire/Cables

| Qty | Description | Price | Source / Part No. |
|---|---|---|---|
| 1 | Cable Matters 2-Pack Ultra Thin HDMI Cable 3 ft |  | https://www.amazon.com/dp/B00T58JH98?ref=ppx_yo2ov_dt_b_fed_asin_title&th=1 |
|  | Official Pi DSI Display FPC Flexible Cable for Raspberry Pi 5, 22Pin to 15Pin |  | https://www.amazon.com/dp/B0D12N6TLW?ref=ppx_yo2ov_dt_b_fed_asin_title |
|  | Arducam for Raspberry Pi Zero Camera Cable Set, 1.5" 2.87" 5.9" Ribbon Flex Extension Cables for Pi Zero&W |  | https://www.amazon.com/dp/B085RW9K13?ref=ppx_yo2ov_dt_b_fed_asin_title&th=1 |
|  | 6" left angle HDMI to HDMI male to male cable | $12.48 | https://www.amazon.com/dp/B08QFMJC43?ref=ppx_yo2ov_dt_b_fed_asin_title&th=1 |
|  | Poyiccot HDMI Panel Coupler Adapter Connector, (2-Pack)  HDMI Female to Female Inline Straight Coupler |  | https://www.amazon.com/dp/B071LDPR8H?ref_=ppx_hzsearch_conn_dt_b_fed_asin_title_6 |
|  | Power jack cable assembly Tensility  10-03609  Cable Assembly 2.1mm ID, 5.5mm OD Jack to Wire Leads Flat 1.00' (305.00mm) |  | digikey 839-10-03609-ND |
|  | Kondor Blue USB-A to USB-C 3.0 Right Angle Cable (2', Blue) |  | KOUSBCARA2 B&H Photo |

## Hardware

| Qty | Description | Price | Source / Part No. |
|---|---|---|---|
| 3 | Shoulder Bolt 5 mm Shoulder Diameter, 6 mm Shoulder Length, M4 x 0.7 mm Thread ( |  | https://www.mcmaster.com/92981A146/ |
| 3 | Shoulder Bolt  5 mm Shoulder Diameter, 10 mm Shoulder Length, M4 x 0.7 mm Thread |  | https://www.mcmaster.com/92981A030/ |
| 1 | Alloy Steel Low-Profile Socket Head Screw, Hex Drive, M4 x 0.7 mm Thread, 10 mm Long (pack of 50) |  | https://www.mcmaster.com/93070A101/ |
| 1 | Black-Oxide Alloy Steel Hex Drive Flat Head Screw, 90 Degree Countersink, M2 x 0.4 mm Thread Size, 8 mm Long (pack of 25) |  | https://www.mcmaster.com/91294A005/ |
|  | Black-Oxide Alloy Steel Hex Drive Flat Head Screw, 90 Degree Countersink, M2 x 0.4 mm Thread Size, 16 mm Long |  | https://www.mcmaster.com/91294A538/ |
| 1 | Black-Oxide Alloy Steel Hex Drive Flat Head Screw, 90 Degree Countersink, M2 x 0.4 mm Thread Size, 12 mm Long (pack of 25) |  | https://www.mcmaster.com/91294A009/ |
|  | Black-Oxide Alloy Steel Hex Drive Flat Head Screw, 90 Degree Countersink, M2.5 x 0.45 mm Thread Size, 20 mm Long (pack of 25) |  | https://www.mcmaster.com/91294A024/ |
|  | Alloy Steel Low-Profile Socket Head Screw, Hex Drive, M3 x 0.5 mm Thread, 10 mm Long(pack of 25) |  | https://www.mcmaster.com/93070a067/ |
|  | Black-Oxide Alloy Steel Hex Drive Flat Head Screw, 90 Degree Countersink, M3 x 0.5 mm Thread Size, 10 mm Long |  | https://www.mcmaster.com/91294A130/ |
|  | Alloy Steel Low-Profile Socket Head Screw, Hex Drive, M4 x 0.7 mm Thread, 12 mm Long |  | https://www.mcmaster.com/93070A103/ |
|  | Black-Oxide Medium-Strength Steel Hex Nut, ISO Class 8, M2.5 x 0.45 mm Thread Size (pack of 50) |  | https://www.mcmaster.com/90593A025/ |
|  | Black-Oxide Alloy Steel Hex-Drive Flat Head Screw, 90 Degree Countersink, M2.5 x 0.45 mm Thread Size, 5 mm Long 25 pk | $7.48 | https://www.mcmaster.com/91294A012/ |
|  | Corrosion-Resistant Black-Oxide 18-8 Stainless Steel Hex Nut, M3 x 0.5 mm Thread Size (pack of 100) |  | https://www.mcmaster.com/98676A100/ |
|  | Button Head Hex Drive Screw, Black-Oxide Alloy Steel, M5 x 0.80 mm Thread, 8 mm Long (pack of 100) |  | https://www.mcmaster.com/91239A222/ |
|  | Dowel pin 52100 Alloy Steel, 3 mm Diameter, 16 mm Long |  | https://www.mcmaster.com/91595A116/ |
|  | Brass Tapered Heat-Set Inserts for Plastic, M4 x 0.7 mm Thread Size, 4.7 mm Installed Length (pack of 100) |  | https://www.mcmaster.com/94180a351/ |
|  | High-Strength Ultra-Quiet Timing Belt Curved Teeth, 6 mm Wide, 200-2P-06, Gates Powergrip Gt |  | https://www.mcmaster.com/7947K729/ |
|  | Expandable Sleeving, 1/4" ID (10ft) |  | https://www.mcmaster.com/9284k612/ |
|  | 10 ft 1/4' Techflex |  | https://www.mcmaster.com/2837K72/ |
| 2 | High-Density Polyethylene (HDPE) Plastic Sheet 1/4" Thick 8" X 12"- Black HDPE Sheet |  | https://www.amazon.com/dp/B0DMNX8P6V?psc=1&ref_=cm_sw_r_em_ud_ct_HHQBS94ZW5EZRYS1JNPQ |
| 1 | Lesnlok 12 x 16 White Translucent Acrylic Sheet 1/8 inch Thick 3mm | $21.98 | https://www.amazon.com/dp/B0G4JF22YK?ref_=ppx_hzsearch_conn_dt_b_fed_asin_title_1&th=1 |
| 1 | Cast Acrylic Sheet, Transparent Light White, 12" x 12" x 0.236" (6mm) Size |  | https://www.amazon.com/dp/B006FLZ1NO?ref=ppx_yo2ov_dt_b_fed_asin_title |
|  | ruthex M4 Threaded Inserts Short |  | https://www.amazon.com/dp/B09MTTC7S9?ref_=ppx_hzsearch_conn_dt_b_fed_asin_title_2&th=1 |
|  | ruthex M3 Threaded Inserts VORON - 100 Pieces RX-M3x5x4 |  | https://www.amazon.com/dp/B0CDH36ZMX?ref_=ppx_hzsearch_conn_dt_b_fed_asin_title_3&th=1 |
|  | ruthex M5 Threaded Inserts Short - 50 Pieces RX-M5Sx5.8 Brass Heat Set Insert |  | https://www.amazon.com/dp/B09MTRT9T7?ref_=ppx_hzsearch_conn_dt_b_fed_asin_title_3&th=1 |
| 1 | ruthex Threaded Inserts M2 + M3 + M4 + M5 Assortment Box | $29.99 |  |
|  | BREADBOARD DIN RAIL MOUNT PTH  DMB-4769-CB 3.42" L x 0.56" W (86.9mm x 14.3mm) |  | https://www.digikey.com/en/products/detail/bud-industries/DMB-4769-CB/6024687 |

## Printed and Fabricated Parts (CAD in this repo)

Custom parts are provided as STEP files in the subsystem folders (see `../README.md`). Print in PETG (black unless noted); optical or diffusing parts are noted below. Material/colour entries are the author's working choices.

| Part (STEP file) | Qty | Material / process |
|---|---|---|
| `Drive Base and Frame/` base, top plate, motor tensioning plate | 1 each | 3D printed (black PETG) |
| `Carousel Assembly/` six-plate carousel, adjustable bearing arms, motor base block | 1 each | 3D printed (black PETG) |
| `Carousel Assembly/acrylic plate diffuser` | 1 | Translucent white acrylic sheet, cut and drilled (use hole-drilling jig) |
| `Carousel Assembly/magnet carousel position sensor trigger` | 1 per plate position | 3D printed; holds an 8 mm magnet |
| `Carousel Assembly/optical carousel position sensor trigger 14.5 mm printed stripe long` | 1 | 3D printed (optical flag for ITR20001/T) |
| `Miscellaneous Hardware/` acrylic diffuser hole-drilling jig, spindle heat-set insert installation jig | 1 each | 3D printed fabrication aids |
| `Miscellaneous Hardware/` corner bracket | as needed | 3D printed |
| `Miscellaneous Hardware/` M5 thumb screws (15 mm, 25 mm) | as needed | 3D printed |
| `Miscellaneous Hardware/` 2020 T-slot end cap with cover, T-slot cover wire guide, 8 mm cable guide | as needed | 3D printed |
| `Miscellaneous Hardware/` 100 x 15 mm square Petri dish magnetic fastener | 1 per plate position | 3D printed; holds an 8 mm magnet |
| `Controller Enclosure/`, `Camera and Controller Mount/` (incl. Picamera mount), `Rear Illuminator/` | 1 each | 3D printed (black PETG) |

## Magnets

| Qty | Description | Price | Source / Part No. |
|---|---|---|---|
|  | 8 mm x 3 mm neodymium disc magnets, N35 (Petri dish fasteners and carousel position triggers) |  | https://www.amazon.com/dp/B0G1SXK3VY |

## Additional McMaster-Carr Parts Referenced in the CAD Model

These part numbers appear as components in the full-assembly CAD model but were not yet listed above. Sizes, quantities and pack sizes should be confirmed against the model (open the part in Fusion or check the McMaster page) before ordering.

| Qty | McMaster-Carr No. | Description | Source |
|---|---|---|---|
|  | 2349K786 | Permanently Lubricated Ball Bearing | https://www.mcmaster.com/2349K786/ |
|  | 8215K206 | Load-Rated Adhesive-Back Sorbothane Bumper | https://www.mcmaster.com/8215K206/ |
|  | 90591A250 | Zinc-Plated Steel Hex Nut | https://www.mcmaster.com/90591A250/ |
|  | 90591A255 | Zinc-Plated Steel Hex Nut | https://www.mcmaster.com/90591A255/ |
|  | 90591A260 | Zinc-Plated Steel Hex Nut | https://www.mcmaster.com/90591A260/ |
|  | 90591A270 | Zinc-Plated Steel Hex Nut | https://www.mcmaster.com/90591A270/ |
|  | 90593A001 | Black-Oxide Medium-Strength Steel Hex Nut | https://www.mcmaster.com/90593A001/ |
|  | 90593A004 | Black-Oxide Medium-Strength Steel Hex Nut | https://www.mcmaster.com/90593A004/ |
|  | 91239A113 | Button Head Hex Drive Screw | https://www.mcmaster.com/91239A113/ |
|  | 91239A115 | Button Head Hex Drive Screw | https://www.mcmaster.com/91239A115/ |
|  | 91239A117 | Button Head Hex Drive Screw | https://www.mcmaster.com/91239A117/ |
|  | 91239A224 | Button Head Hex Drive Screw | https://www.mcmaster.com/91239A224/ |
|  | 91239A228 | Button Head Hex Drive Screw | https://www.mcmaster.com/91239A228/ |
|  | 91239A232 | Button Head Hex Drive Screw | https://www.mcmaster.com/91239A232/ |
|  | 91239A704 | Button Head Hex Drive Screw | https://www.mcmaster.com/91239A704/ |
|  | 91287A126 | 18-8 Stainless Steel Hex Head Screw | https://www.mcmaster.com/91287A126/ |
|  | 91290A083 | Black-Oxide Alloy Steel Socket Head Screw | https://www.mcmaster.com/91290A083/ |
|  | 91290A144 | Black-Oxide Alloy Steel Socket Head Screw | https://www.mcmaster.com/91290A144/ |
|  | 91290A180 | Black-Oxide Alloy Steel Socket Head Screw | https://www.mcmaster.com/91290A180/ |
|  | 91290A264 | Black-Oxide Alloy Steel Socket Head Screw | https://www.mcmaster.com/91290A264/ |
|  | 92314A646 | 18-8 Stainless Steel Hex Head Screw | https://www.mcmaster.com/92314A646/ |
|  | 93070A064 | Alloy Steel Low-Profile Socket Head Screw | https://www.mcmaster.com/93070A064/ |
|  | 93070A098 | Alloy Steel Low-Profile Socket Head Screw | https://www.mcmaster.com/93070A098/ |
|  | 97259A103 | Low-Strength Steel Thin Square Nut | https://www.mcmaster.com/97259A103/ |
|  | 98687A308 | General Purpose Steel Washer | https://www.mcmaster.com/98687A308/ |

## ARUCO markers

| Qty | Description | Price | Source / Part No. |
|---|---|---|---|
|  | avery 4397 Avery Printable Sticker Paper, 8.5" x 11", Glossy Clear, Permanent Adhesive, Laser/Inkjet Compatible |  |  |

## 2020 Extrusion Rail Cut List

Cut list for the `4pcs 500mm T-Slot 2020 Aluminum Extrusion` stock ordered above:

- 1 500mm horizonal main rail
- 1 300mm vertical camera/light shield rail
- 2 200 mm horizontal light shield rails
- 2 150 mm vertical camera and controller rails tap ends for M6
- 4 150mm horizonal support rails for LED illumination panel and motor hub supports

## Camera Housing Hardware

- 4 M2 2mm length d1 3.2 d2 2.7mm brass Ktehloy  heat set inserts
- 4 10 mm M2 standoffs
- 4 M2.5  8mm flat head
- 4 M2.5 hex nuts
- 1 arducam CSI to HDMI UC-392(B0091) board
- 37mm 37 mm Infrared Infra-Red IR Filter 850nm 850
- Green Leaf 37mm Infrared IR Pass Filter 850nm for DSLR Camera Lens Photography

## Controller Board Connectors

| Description | Qty | Part No. |
|---|---|---|
| BIGTREETECH TMC2209 V1.3 UART Stepper Motor Driver 2.8A pk of 2 | 1 | https://www.amazon.com/dp/B08SMDY3SQ?ref=ppx_yo2ov_dt_b_fed_asin_title&th=1 |
| CONN HDR 8POS 0.1 GOLD PCB | 2 | S7041- ND Digikey |
| Molex 0022112082 Connector Header Through Hole 8 position 0.100" (2.54mm) | 2 | 900-0022112082-ND Digikey |
| Molex 0022013087 8 Position Rectangular Housing Connector Receptacle White 0.100" (2.54mm) |  | WM2006-ND Digikey |
| Molex 0022112062 Connector Header Through Hole 6 position 0.100" (2.54mm) |  | WM2704-ND |
| Molex 0022012067  6 Position Rectangular Housing Connector Receptacle White 0.100" (2.54mm) |  | WM2015-ND |
| Molex 0022112032 Connector Header Through Hole 3 position 0.100" (2.54mm) |  | WM2701-ND |
| Molex 0010112033 3 Position Rectangular Housing Connector Receptacle White 0.100" (2.54mm) |  | WM2602-ND |
| Molex 0022112022 Connector Header Through Hole 2 position 0.100" (2.54mm) |  | WM2700-ND |
| Molex 0022012027 2 Position Rectangular Housing Connector Receptacle White 0.100" (2.54mm) |  | WM20011-ND |
| Molex 0008550102 Non-Gendered Contact Gold 22-30 AWG Crimp | ? | WM2312-ND Digikey |
| Phoenix Contact  8 Position Terminal Block Header, Male Pins Green, Panel Mount |  | 277-1096146-ND Digikey |
| Phoenxi Contact 8 Position Terminal Block Plug, Female Socket (5.08mm) Free Hanging |  | 277-5734-ND Digikey |
| Power Barrel Connector Jack 2.10mm ID (0.083"), 5.50mm OD (0.217") Panel Mount |  | 839-54-00151-ND Digikey |
| thermal glue |  | https://www.amazon.com/dp/B07HCDRL7W?ref_=ppx_hzsearch_conn_dt_b_fed_asin_title_1&th=1 |

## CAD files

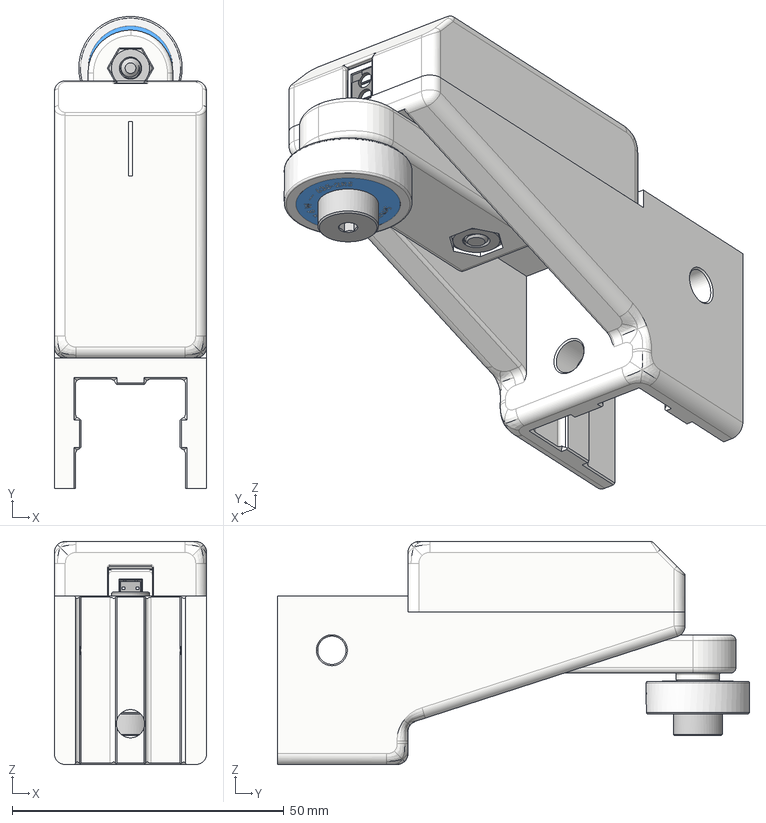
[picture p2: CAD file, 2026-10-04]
hardware/CAD Files/Carousel Assembly/Adjustable bearing and optical sensor assembly_dual bearing.step
28.0 x 86.8 x 41.0 mm
90591A255_Zinc-Plated Steel Hex Nut x 2
p BEARING, METRIC 600 MINIATURE SERIES, DOUBLE-SEALED 5mm ID × 19 OD × 6 W — 635-2RS
92981A146_Alloy Steel Shoulder Screws
93070A103_Alloy Steel Low-Profile Socket Head Screw

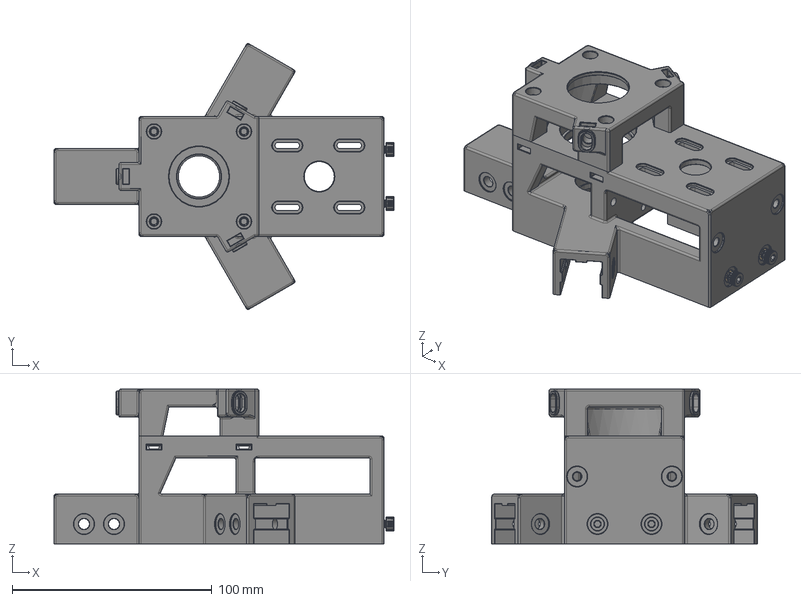
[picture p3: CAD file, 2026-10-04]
hardware/CAD Files/Carousel Assembly/dual bearing belt drive_motor base block.step
170.0 x 133.0 x 77.5 mm
RX-M4x8.1 x 2

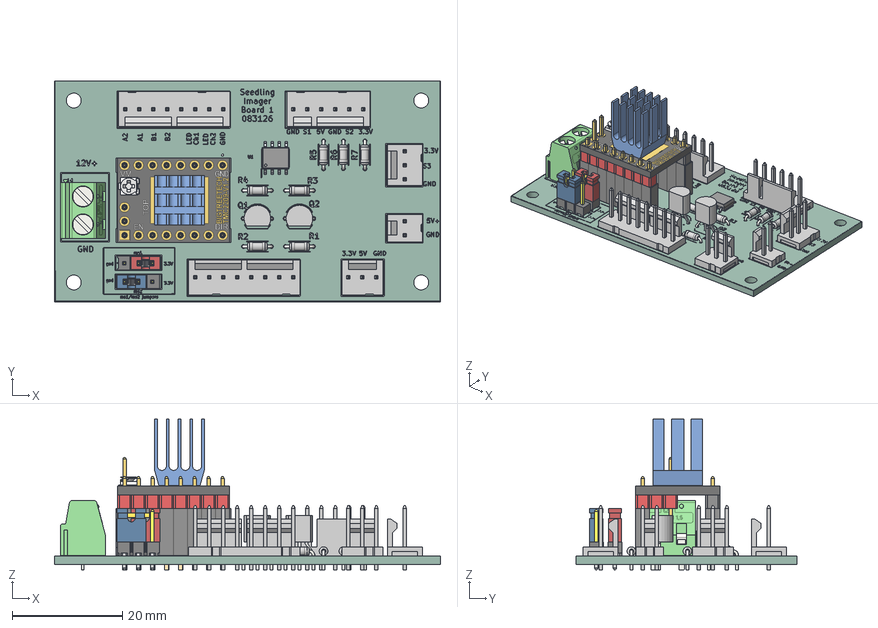
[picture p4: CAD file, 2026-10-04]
hardware/CAD Files/Controller Subassembly/Seedling Imager board_1.step
70.0 x 40.0 x 27.3 mm

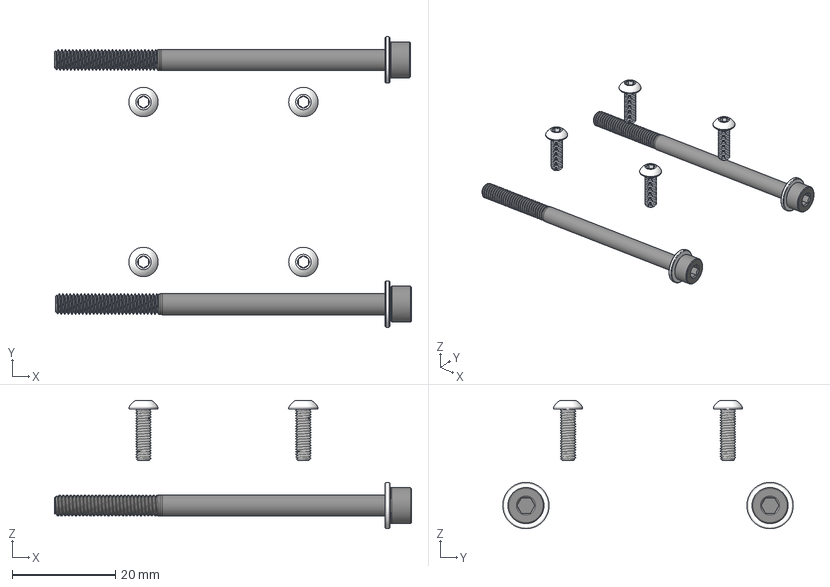
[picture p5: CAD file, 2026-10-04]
hardware/CAD Files/Drive Base and Frame/top plate.step
69.2 x 56.3 x 24.9 mm

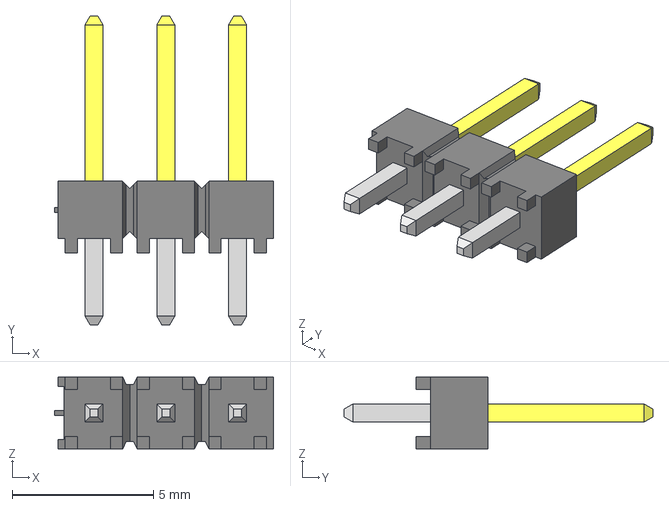
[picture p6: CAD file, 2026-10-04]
hardware/Electronics/Seedling Imager board_1/TSW_103_07_L_S/CON3_1X3_TU_TSW.stp
7.75 x 10.9 x 2.54 mm

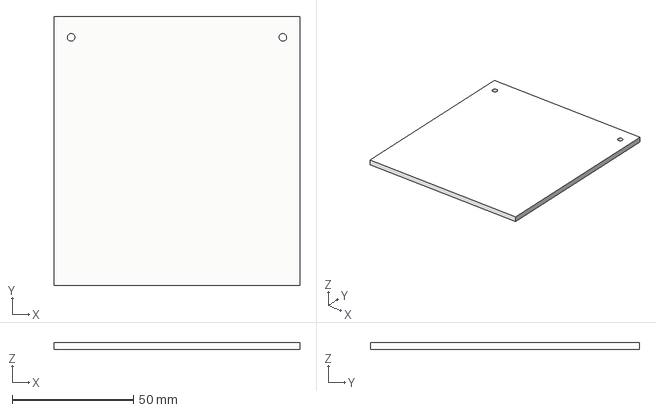
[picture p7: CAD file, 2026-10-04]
hardware/CAD Files/Carousel Assembly/acrylic plate diffuser.step
101.6 x 111.1 x 3.00 mm

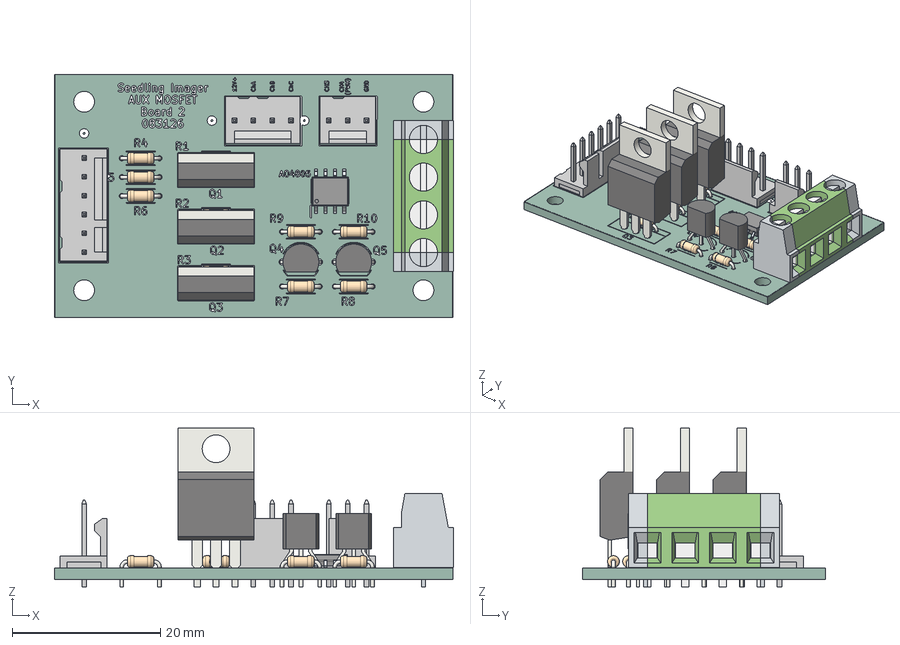
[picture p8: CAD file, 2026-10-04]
hardware/CAD Files/Controller Subassembly/Seedling Imager board_2.step
53.8 x 32.8 x 21.4 mm

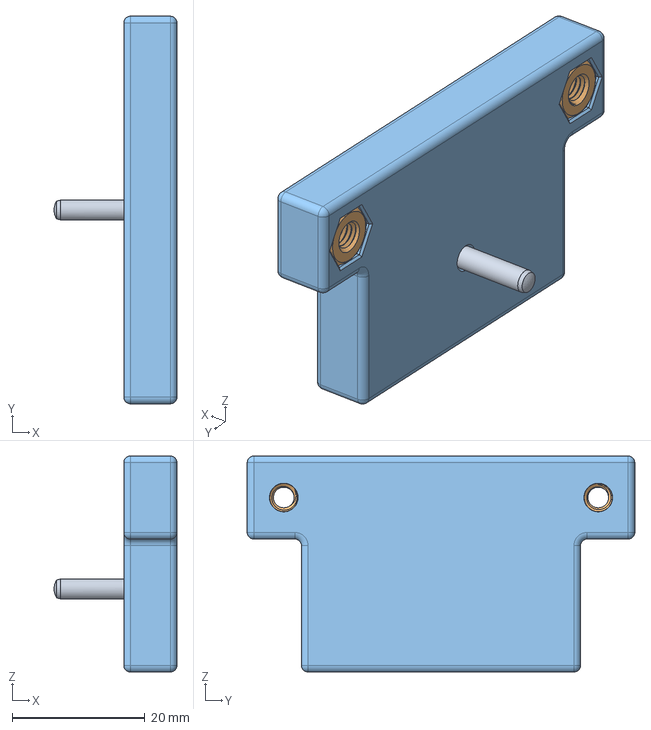
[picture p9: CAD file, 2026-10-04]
hardware/CAD Files/Drive Base and Frame/motor tensioning plate.step
18.5 x 58.3 x 32.5 mm
91595A116_Dowel Pin
90591A255_Zinc-Plated Steel Hex Nut x 2

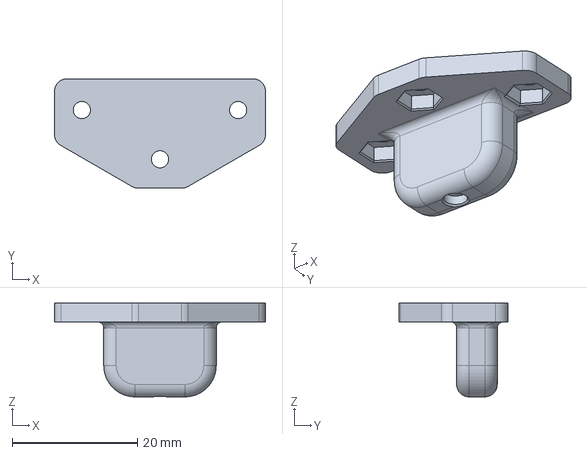
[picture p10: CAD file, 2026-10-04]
hardware/CAD Files/Carousel Assembly/magnet carousel position sensor trigger.step
33.8 x 17.5 x 15.0 mm

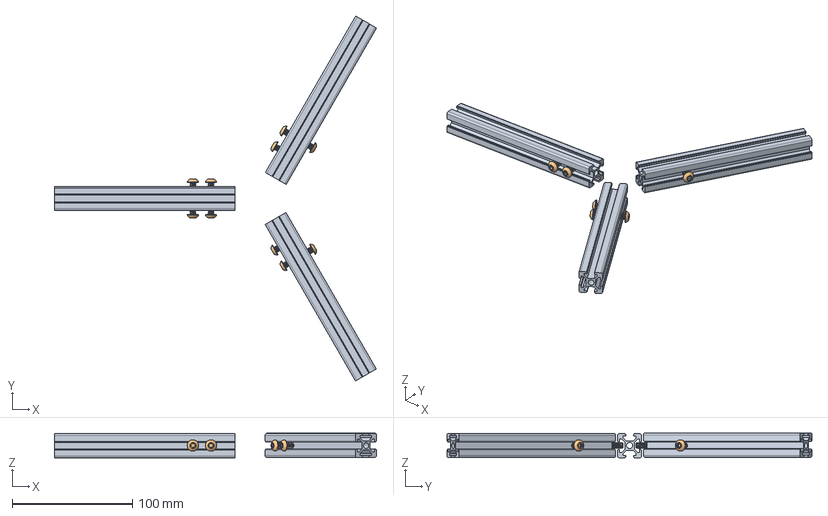
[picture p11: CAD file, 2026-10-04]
hardware/CAD Files/Drive Base and Frame/base.step
267.5 x 303.0 x 20.5 mm
Al2020_T_Slot x 3

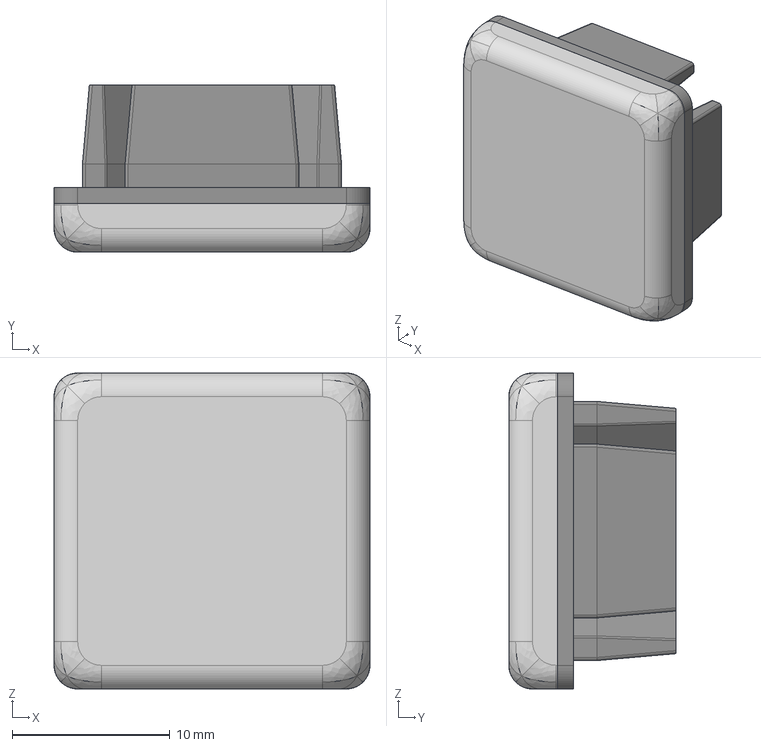
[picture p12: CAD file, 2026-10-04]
hardware/CAD Files/Miscellaneous Hardware/2020 T-slot End Cap with cover.step
20.0 x 10.6 x 20.0 mm

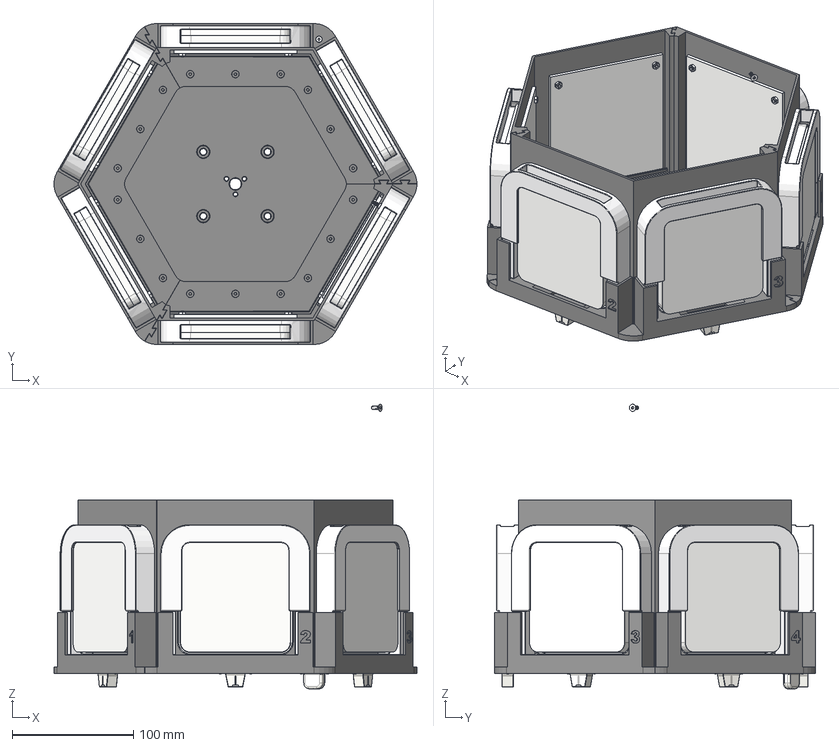
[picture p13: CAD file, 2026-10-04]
hardware/CAD Files/Carousel Assembly/six plate 120 mm carousel_dual bearing belt drive.step
299.4 x 264.8 x 234.8 mm
plate holder cover
white stripe x 6
90593A025_Black-Oxide Medium-Strength Steel Hex Nut_1 x 12
91294A034_Black-Oxide Alloy Steel Hex Drive Flat Head Screw x 12
lid x 6
plate holder x 6
RadialMagnets_9406_disc_8x3mm_N35 x 12
90593A025_Black-Oxide Medium-Strength Steel Hex Nut x 3
acrylic plate diffuser x 6

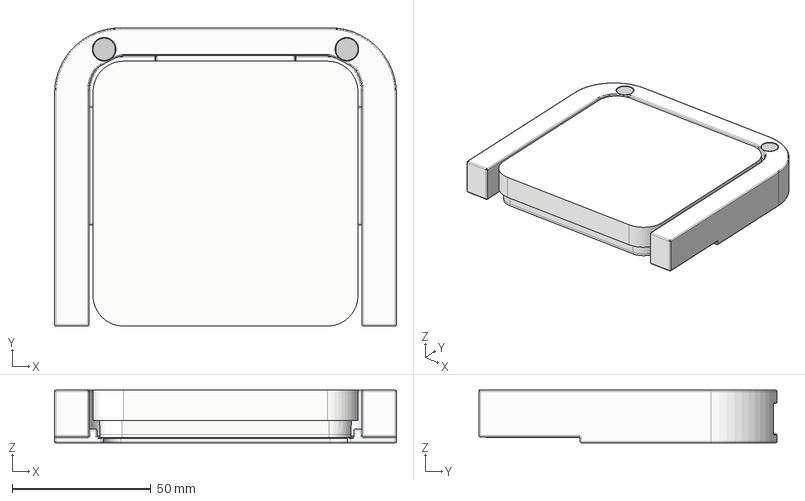
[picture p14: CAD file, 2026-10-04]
hardware/CAD Files/Miscellaneous Hardware/100mm x 15 mm square petri dish magnetic fastener_8mm magnet.step
123.3 x 107.5 x 19.0 mm
lid
plate holder
RadialMagnets_9406_disc_8x3mm_N35 x 2

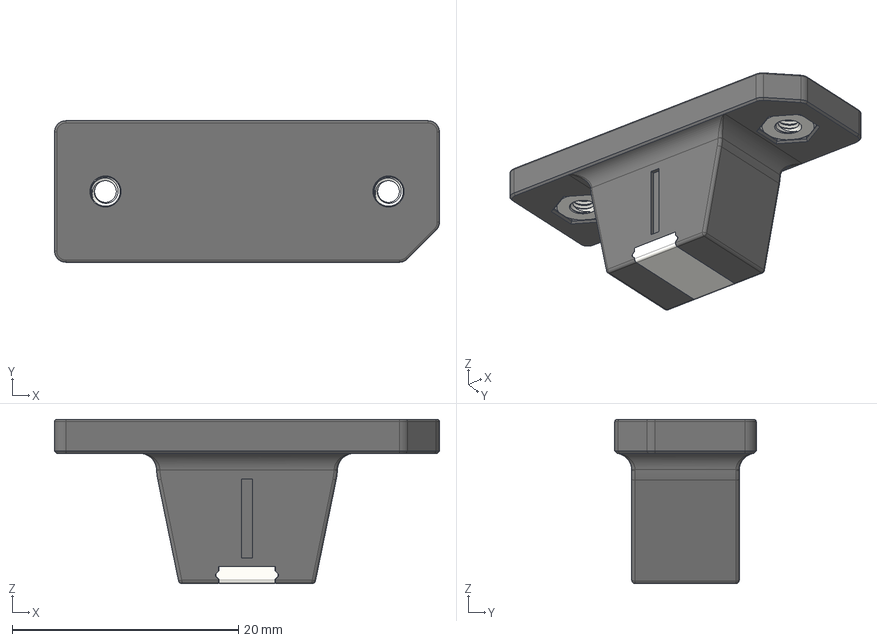
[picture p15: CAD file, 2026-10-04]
hardware/CAD Files/Carousel Assembly/optical carousel position sensor trigger 14.5 mm printed stripe long.step
34.0 x 12.5 x 14.5 mm
white stripe
90593A025_Black-Oxide Medium-Strength Steel Hex Nut x 2

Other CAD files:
hardware/CAD Files/Miscellaneous Hardware/acrylic plate diffuser_hole drilling jig.step
hardware/CAD Files/Miscellaneous Hardware/corner bracket.step
hardware/CAD Files/Carousel Assembly/Adjustable bearing arm_mag sensor_dual bearing.step
hardware/CAD Files/Miscellaneous Hardware/2020_8mm dia_cable guide.step
hardware/CAD Files/Miscellaneous Hardware/2020 T-Slot cover_wire guide.step
hardware/CAD Files/Miscellaneous Hardware/M5_thumb screw 15mm.step
hardware/CAD Files/Miscellaneous Hardware/M5_thumb screw 25mm.step
hardware/CAD Files/Miscellaneous Hardware/Meanwell LRS-100-12 enclosure.step
hardware/CAD Files/Miscellaneous Hardware/spindle_heat set insert install_ jig.step

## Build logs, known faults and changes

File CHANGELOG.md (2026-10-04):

<
# Changelog

## v1.3.2 — 2026-10-04
- **Hardware**: renamed the IR filter holder component to "850 nm long-pass filter holder" (Fusion archive and STEP files); clarified camera-mount contents in `hardware/README.md`; updated BOM.
- Updated root README, CHANGELOG and citation. Software unchanged from v1.3.0. Archived on Zenodo: 10.5281/zenodo.23144486.

## v1.3.1 — 2026-10-04
- **Hardware**
  - Added complete hardware design files under `hardware/`: full-assembly STEP (zipped), individual part STEP files by subsystem, KiCad 10 files for board 1, board 2 and the hall sensor board, bill of materials, and assembly render.
  - Hardware licensed under CERN-OHL-S v2 (`hardware/LICENSE-CERN-OHL-S-v2.txt`, `hardware/NOTICE.txt`).
  - Fusion archive (`.f3z`) and full-assembly STEP are distributed as GitHub Release assets (over the 100 MB repository file limit).
- **Licensing**: added root `LICENSE` (MIT) for the software.
- Software unchanged from v1.3.0. Archived on Zenodo: 10.5281/zenodo.23143807.

## v0.06 — 2026-01-08
- **Camera & Imaging**
  - Dual-stream Picamera2 config: full-res TIFF (4608×2592) + lores preview (640×360).
  - Lossless TIFF saving via `tifffile` (zlib compression).
  - AF helpers: Continuous AF in Live View; single AF trigger during settle.
  - AE lock/unlock: AE enabled during settle; disabled before capture for consistency.
- **Experiment Runner**
  - Per-plate sequence: LED ON → AF → 10 s settle → capture → LED OFF → advance.
  - Post-cycle wait after Plate 6, then start next cycle at Plate 1.
  - **CSV metadata logging** (`metadata.csv`): timestamp, cycle, plate, illumination, path, dimensions, size, AE, exposure, gain, AWB.
- **GUI**
  - **Camera Config dialog** with persisted settings (`camera_settings.json`).
  - **File Manager**: toolbar actions, thumbnails with robust TIFF fallback, per-plate filter, CSV tab & Open CSV.
  - **Experiment Setup**: storage estimate + free-space warning.
  - Live View stability and LED control restored; last-saved-image preview after capture.
- **Autostart & Launcher**
  - Systemd user service (`seedling-imager.service`) and desktop autostart entry.
  - Desktop launcher icon (`Seedling-Imager.desktop`).

---

## v0.05 — 2025-12-30
- **New:** `experiment_runner.py` to schedule time-lapse imaging cycles.
  - Per-plate sequence: illumination ON → 10 s settle → capture (if selected) → illumination OFF → advance.
  - Wait begins immediately after Plate 6, then next cycle starts at Plate 1.
  - Signals:
    - `image_saved_signal(path)` → GUI shows last captured image.
    - `settling_started(plate_idx)`/`settling_finished(plate_idx)` → optional live preview during settle.
- **GUI:**
  - Shows *last saved image* after each capture (helps remote users).
  - Optional live preview during settle period.
  - Homing terminology and dual illumination toggle (Green @ GPIO12, IR @ GPIO13).
  - “End Experiment” button aborts the thread gracefully.
- **Motor control:**
  - `advance()` now always reports drift correction when wrapping to Plate #1 (including “0 extra steps”).
- **Experiment Setup:**
  - Two-row plate selection; visible checkbox outlines; illumination selector with color (teal = Green, deep red = IR).
- **Camera:**
  - `save_image(path)` helper saves PNG/JPEG with correct color ordering.

## v0.04 — 2025-12-30
- Homing rename; dual-LED support; initial experiment loop scaffolding.

## v0.03 — 2025-12-30
- UI refinements; illumination selector; plate layout and sizing fixes; basic homing and drift code paths.

``
 >

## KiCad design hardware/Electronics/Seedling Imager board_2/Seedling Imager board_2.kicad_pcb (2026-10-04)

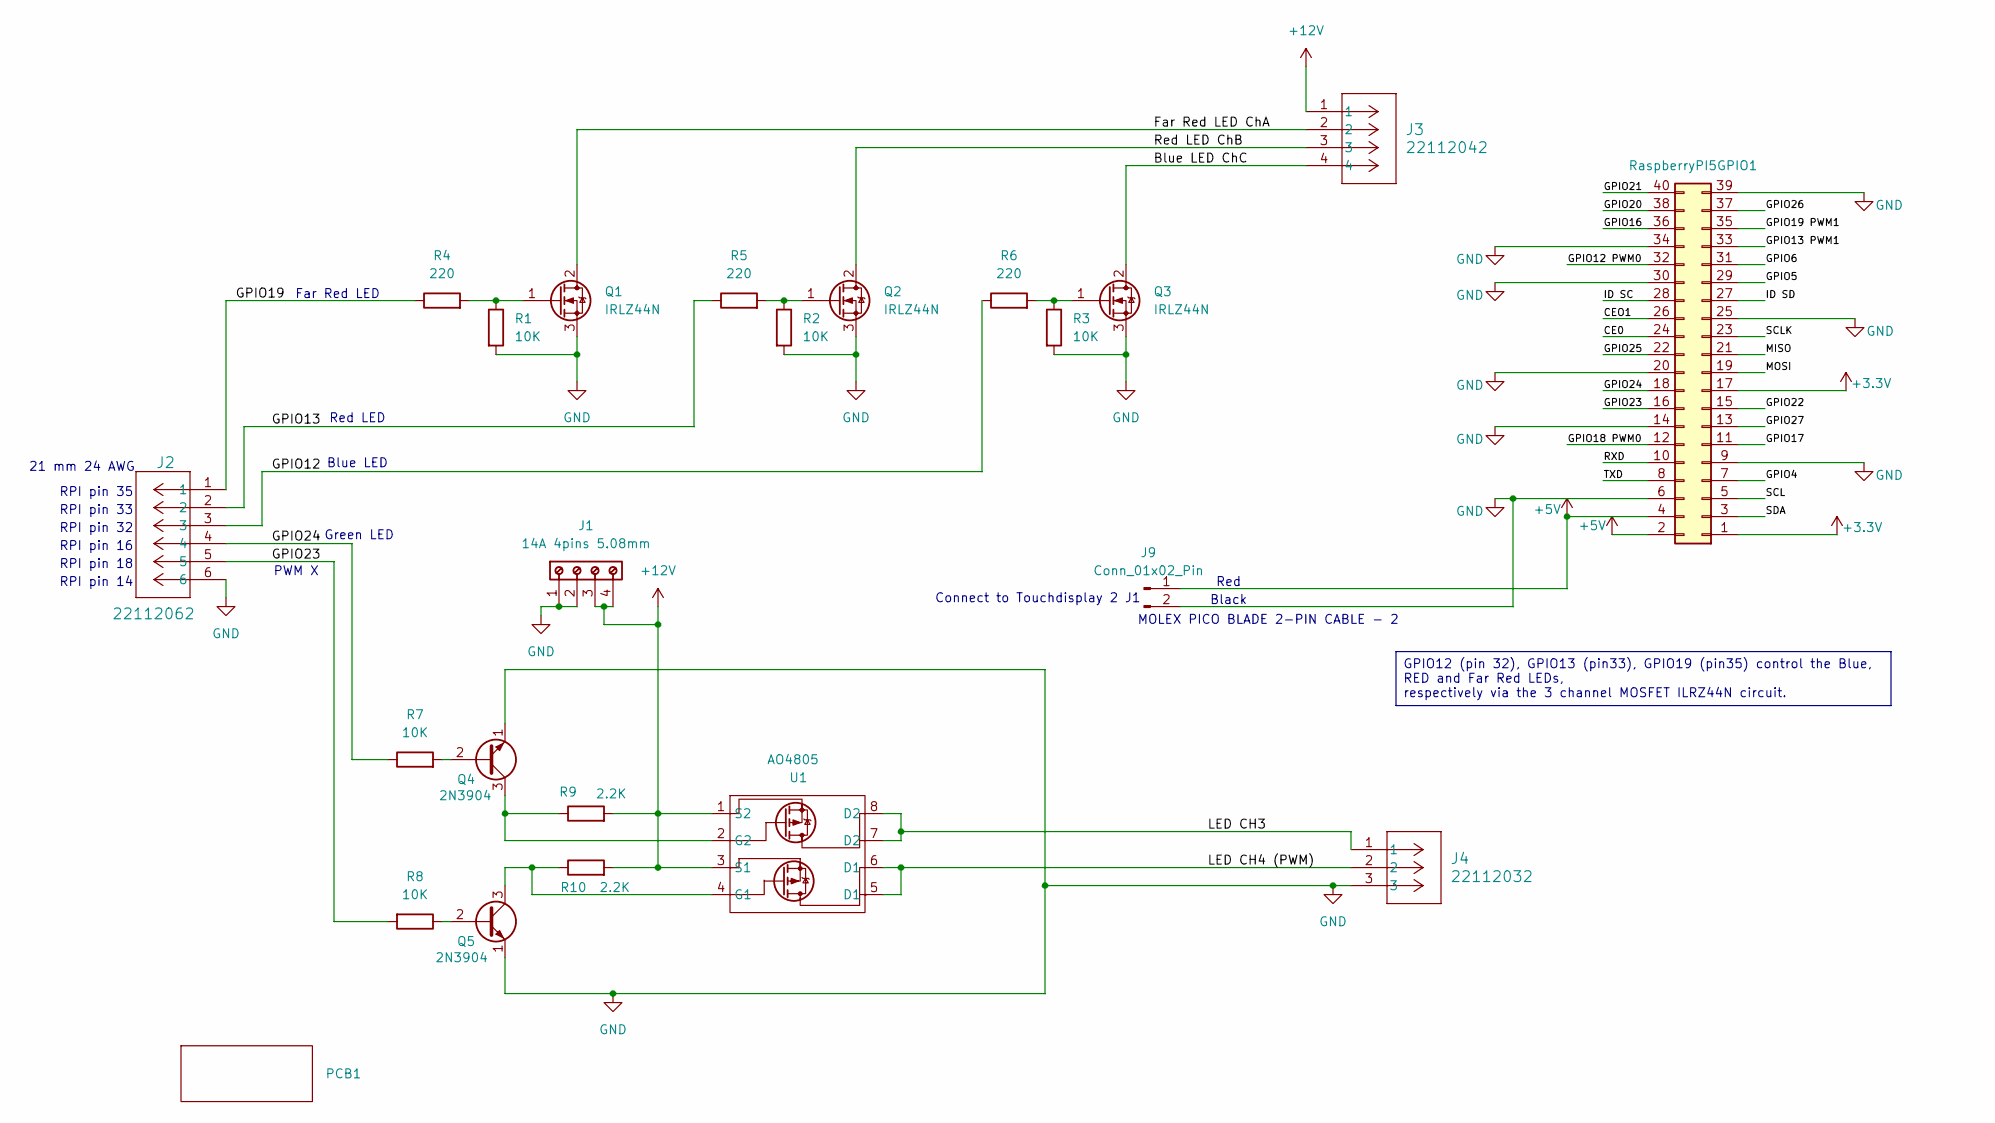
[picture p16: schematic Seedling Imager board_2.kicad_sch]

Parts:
J1: 691241510004; J_Wurth_WR-TBL_691241510004; Part Number 691241510004
J2: 22112062; CONN_A-6373-06A_MOL
J3: 22112042; CONN_A-6373-04A_MOL
J4: 22112032; CONN_A-6373-03A_MOL
J9: Conn_01x02_Pin
PCB1: DMB-4770-CB_cut
Q1, Q2, Q3: IRLZ44N; TO-220-3_Vertical
Q4, Q5: 2N3904; TO-92_Inline_Wide
R1, R2, R3, R7, R8: 10K; R_Axial_DIN0204_L3.6mm_D1.6mm_P5.08mm_Horizontal
R4, R5, R6: 220; R_Axial_DIN0204_L3.6mm_D1.6mm_P5.08mm_Horizontal
R9, R10: 2.2K; R_Axial_DIN0204_L3.6mm_D1.6mm_P5.08mm_Horizontal
RaspberryPI5GPIO1: Conn_02x20_Odd_Even; RHDR40W60P250_2X20_5100X500X23
U1: AO4805; SOIC127P600X175-8N

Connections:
+12V: J1.3, J1.4, J3.1, R9.2, R10.2, U1.1 (S2), U1.3 (S1)
/Blue LED ChC: J3.4, Q3.2 (D)
/Far Red LED ChA: J3.2, Q1.2 (D)
/GPIO12: J2.3, R6.1
/GPIO13: J2.2, R5.1
/GPIO19: J2.1, R4.1
/GPIO23: J2.4, R7.1, RaspberryPI5GPIO1.18
/GPIO24: J2.5, R8.2, RaspberryPI5GPIO1.16
/LED CH3: J4.1, U1.7 (D2), U1.8 (D2)
/LED CH4 (PWM): J4.2, U1.5 (D1), U1.6 (D1)
/Red LED ChB: J3.3, Q2.2 (D)
GND: J1.1, J1.2, J2.6, J4.3, J9.2, Q1.3 (S), Q2.3 (S), Q3.3 (S), Q4.1 (E), Q5.1 (E), R1.2, R2.2, R3.2, RaspberryPI5GPIO1.6, RaspberryPI5GPIO1.9, RaspberryPI5GPIO1.14, RaspberryPI5GPIO1.20, RaspberryPI5GPIO1.25, RaspberryPI5GPIO1.30, RaspberryPI5GPIO1.34, RaspberryPI5GPIO1.39
unnamed: J9.1, RaspberryPI5GPIO1.2, RaspberryPI5GPIO1.4
unnamed: Q1.1 (G), R1.1, R4.2
unnamed: Q2.1 (G), R2.1, R5.2
unnamed: Q3.1 (G), R3.1, R6.2
unnamed: Q4.2 (B), R7.2
unnamed: Q4.3 (C), R9.1, U1.2 (G2)
unnamed: Q5.2 (B), R8.1
unnamed: Q5.3 (C), R10.1, U1.4 (G1)
unnamed: RaspberryPI5GPIO1.1, RaspberryPI5GPIO1.17

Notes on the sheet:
Connect to Touchdisplay 2 J1
RPI pin 16
RPI pin 33
PWM X
Black
Blue LED
RPI pin 18
21 mm 24 AWG
RPI pin 35
RPI pin 32
Red LED
MOLEX PICO BLADE 2-PIN CABLE - 2
RPI pin 14
Far Red LED
Green LED
Red
GPIO12 (pin 32), GPIO13 (pin33), GPIO19 (pin35) control the Blue, RED and Far Red LEDs, respectively via the 3 channel MOSFET ILRZ44N circuit.

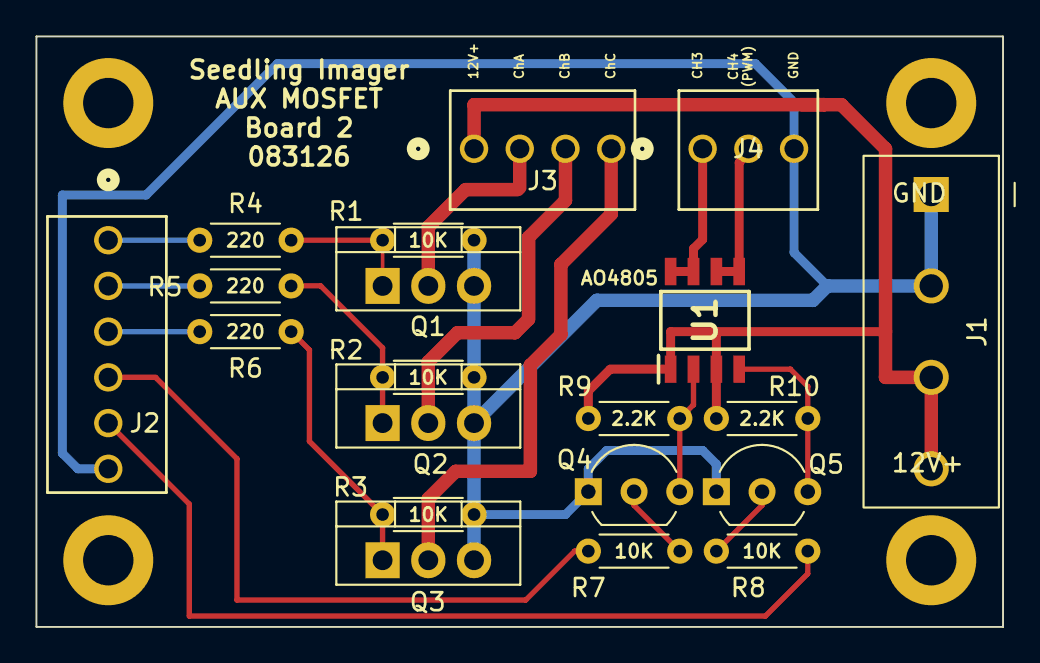
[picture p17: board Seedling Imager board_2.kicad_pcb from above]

Board: 2 copper layers, 53.7 x 32.8 mm, 21 parts (0 on the bottom side), 19 nets.

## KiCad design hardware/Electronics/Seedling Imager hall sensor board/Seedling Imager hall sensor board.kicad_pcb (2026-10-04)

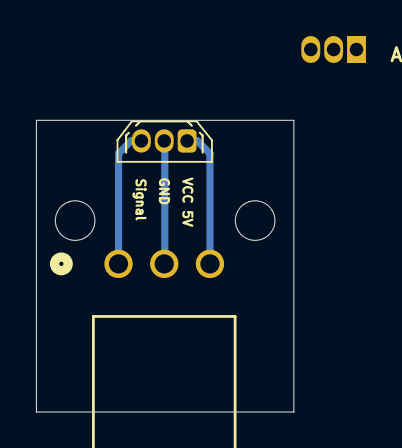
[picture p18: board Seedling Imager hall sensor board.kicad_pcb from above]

Board: 2 copper layers, 14.3 x 16.2 mm, 5 parts (0 on the bottom side), 3 nets.

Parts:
A3144: A1104xLH; TO-92L_Inline
H1, H2: MountingHole; MountingHole_2.2mm_M2
J1: 22053031; CONN_A-7478-03A_MOL
U1: A3144; TO-92Flat

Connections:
/GND: J1.2, U1.2 (GND)
/Signal: J1.1, U1.3 (SIGNAL)
/VCC 5V: J1.3, U1.1 (V_{CC})

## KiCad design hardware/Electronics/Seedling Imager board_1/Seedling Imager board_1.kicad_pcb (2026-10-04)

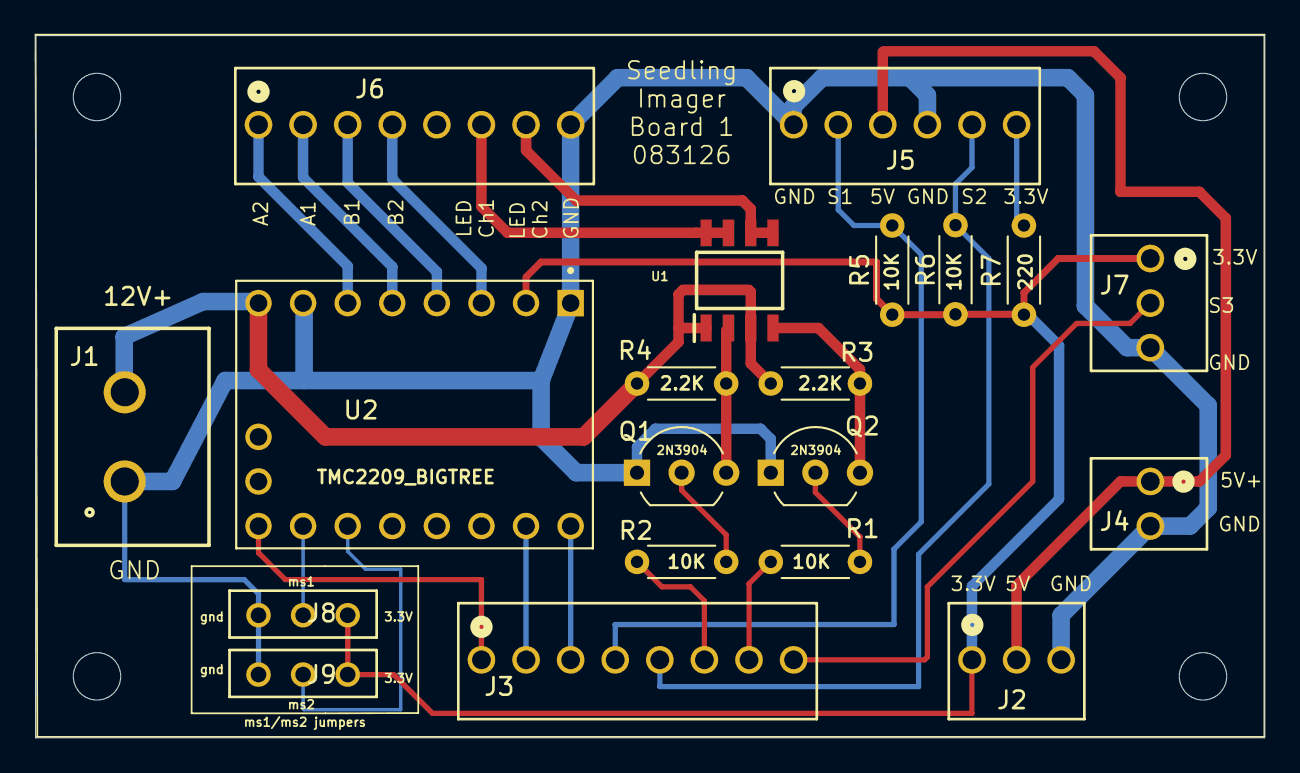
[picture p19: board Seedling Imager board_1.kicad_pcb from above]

Board: 2 copper layers, 70.0 x 40.0 mm, 24 parts (0 on the bottom side), 25 nets.

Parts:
H1, H2, H3, H4: MountingHole; MountingHole_2.7mm
J1: 691313510002; 691311500102
J2, J7: 22112032; CONN_A-6373-03A_MOL
J3, J6: 22112082; CONN_A-6373-08A_MOL
J4: 22112022; CONN_A-6373-02A_MOL
J5: 22112062; CONN_A-6373-06A_MOL
J8, J9: Conn_01x03_Pin; CON3_1X3_TU_TSW
Q1, Q2: 2N3904; TO-92_Inline_Wide
R1, R2, R5, R6: 10K; R_Axial_DIN0204_L3.6mm_D1.6mm_P5.08mm_Horizontal
R3, R4: 2.2K; R_Axial_DIN0204_L3.6mm_D1.6mm_P5.08mm_Horizontal
R7: 220; R_Axial_DIN0204_L3.6mm_D1.6mm_P5.08mm_Horizontal
U1: SOIC127P600X175-8N
U2: TMC2209_BIGTREE; MODULE_TMC2209_BigTreeTech

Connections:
+3.3V (GPIO pin 1): J2.1, J7.1, J8.3, J9.3, R5.2, R6.2, R7.2, U2.2 (VIO)
+5V: J2.2, J4.1, J5.3
+12V: J1.2, R3.1, R4.1, U1.1 (S2), U1.3 (S1), U2.8 (VM)
/black: J6.1, U2.6 (M2A)
/blue: J6.4, U2.3 (M2B)
/green: J6.2, U2.5 (M1A)
/ms1: J8.2, U2.10 (MS1)
/ms2: J9.2, U2.11 (MS2)
/red: J6.3, U2.4 (M1B)
GND: J1.1, J2.3, J4.2, J5.1, J5.4, J6.8, J7.3, J8.1, J9.1, Q1.1 (E), Q2.1 (E), U2.1 (GND), U2.7 (GND)
GPIO6 pin31: J3.8, J7.2
unnamed: J6.6, U1.7 (D2), U1.8 (D2)
unnamed: J6.7, U1.5 (D1), U1.6 (D1)
unnamed: Q1.2 (B), R2.2
unnamed: Q1.3 (C), R4.2, U1.2 (G2)
unnamed: Q2.2 (B), R1.2
unnamed: Q2.3 (C), R3.2, U1.4 (G1)
RPI GPIO16 pin 36: J3.3, U2.16 (DIR)
RPI GPIO17 pin 11: J3.7, R1.1
RPI GPIO20 pin 38: J3.2, U2.15 (STEP)
RPI GPIO21 pin 40: J3.1, U2.9 (~EN)
RPI GPIO22 pin 15 (optical RCV): J3.5, J5.5, R6.1
RPI GPIO26 pin 37 (hall effect): J3.4, J5.2, R5.1
RPI GPIO27 pin 13: J3.6, R2.1
optical TM 3V: J5.6, R7.1

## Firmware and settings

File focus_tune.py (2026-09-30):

#!/usr/bin/env python3
"""
focus_tune.py — quantitative live focus assistant for the Arducam AR2020
mono USB3 camera (stock lens or ACHF080402320MP M12 lens).

By-eye focus is inherently subjective. This script gives you a repeatable,
numeric sharpness score computed from the live image, plus (when run from a
terminal on the Pi's own desktop) an actual live preview window — so you can
first get visually close to focus by watching the Siemens star sharpen up on
screen, then fine-tune to the true maximum using the printed number.

METHOD: "variance of the Laplacian" — a standard, widely-used focus metric.
The Laplacian highlights edges/detail in the image; a blurry image has weak,
smeared edges (low variance), a sharp image has strong, well-defined edges
(high variance). The number has no absolute meaning by itself — it's only
useful as a RELATIVE score to maximize on the SAME scene while you turn the
focus ring. Comparing scores between different scenes/lighting is not
meaningful.

HOW TO USE (see MODES below for which command/illumination to use):
  1. Place the Siemens star (or anything with fine, high-contrast detail —
     printed text, a ruler, seed/tray markings) at your real working
     distance, under whichever illumination matches the mode you're running.
     A blank/uniform surface gives a near-zero, uninformative score
     regardless of focus.
  2. Run this script (see command below). A live preview window opens
     (title "Siemens Star Focus") showing the camera feed with the scored
     region boxed in red and the current/peak sharpness overlaid — watch
     this window and turn the focus ring slowly, using the image itself to
     get roughly close to sharp first.
  3. Once it looks close by eye, switch to watching the printed score in the
     terminal (or the on-image overlay) to nail the true peak: the score
     will rise, peak, and then fall as you sweep through best focus.
     Overshoot past the peak on purpose, then sweep back — the "peak so
     far" value tracks the best you've seen. Bracket it in smaller and
     smaller steps until you're confident you're at the true maximum, not a
     local wobble.
  4. Once you've found the peak, tighten the lock ring (or set screw, on the
     Arducam stock lens) at that exact position. Grip ONLY the lock
     ring/collar while tightening — if the lens itself rotates even
     slightly while you tighten, you'll lose the focus point you just
     found. Recheck the score after tightening in case it shifted, and
     readjust if needed.
  5. Press 'q' or Esc in the preview window, or Ctrl+C in the terminal, to
     stop.

RUN IT (same pattern as camera_arducam_usb3.print_diagnostics()):

    cd ~/Seedling_Imager/seedling_imager_controller
    source venv/bin/activate
    python3 focus_tune.py                 # default: Rear IR (940nm), manual exposure
    python3 focus_tune.py front_visible    # ordinary room light recommended, manual exposure
    python3 focus_tune.py white_front      # front panel White LED strip (GPIO23), manual exposure

NOTE: Fully close the main seedling imager GUI application before running
this (not just "stop Live View" — the GUI holds the GPIO/LED lines and the
camera device open for its entire lifetime, so both need to be free).

NOTE on the live preview window: it needs a real display to draw to, so run
this from a terminal opened on the Pi's own touchscreen/desktop session —
not a plain SSH session with no X forwarding. If no display is available,
the script detects this, prints a warning, and falls back automatically to
writing focus_debug_snapshot.jpg once a second (the original behavior) —
everything else (scoring, LED control) still works the same either way.

MODES:
  rear_ir (default) — drives GPIO27 (Rear IR 940nm panel, same pin gui.py
      uses) and forces the same manual exposure/gain used for real imaging,
      via apply_ir_transmission_preset(). This matches real imaging
      conditions but ONLY makes sense with that illumination — the manual
      exposure/gain values are tuned for that panel's brightness and will
      be wrong (usually far too dark) under any other light source.
  front_visible — for testing with the lens's IR bandpass filter removed
      under ordinary front lighting (to isolate whether a printed target's
      poor contrast is IR-specific). Drives GPIO24 (gui.py's LED_GREEN_PIN)
      as a convenience, but that LED is a deliberately dim service light —
      ordinary room/desk light is a better illuminant for this test. This
      camera's driver rejects true auto-exposure outright, so this mode
      forces manual exposure/gain via the FRONT_VISIBLE_EXPOSURE_US /
      FRONT_VISIBLE_GAIN constants below (edit them if the startup frame
      check shows the image is too dark or too bright).
  white_front — drives GPIO23 (the front panel's White LED strip, same pin
      camera_config.py's "White LED Front" button uses) — a bright, even
      illuminant purpose-built for lighting a Siemens star target during
      manual focus calibration of either camera backend. This is the mode
      to use for the current Arducam stock-lens focus work at ~9.5-10cm
      working distance. Forces manual exposure/gain via the
      WHITE_FRONT_EXPOSURE_US / WHITE_FRONT_GAIN constants below (edit them
      if the startup frame check shows the image is too dark or too
      bright — the white LED is much brighter than front_visible's green
      service light, so these default to a shorter exposure/lower gain).
"""
import sys
import time
import numpy as np
import cv2
import camera_arducam_usb3 as cam

MODE = sys.argv[1] if len(sys.argv) > 1 else "rear_ir"
if MODE not in ("rear_ir", "front_visible", "white_front"):
    print(f"Unknown mode '{MODE}' — use 'rear_ir', 'front_visible', or 'white_front'.")
    sys.exit(1)

# GPIO pins/chip match gui.py's LED_REAR_IR_PIN (27) / LED_GREEN_PIN (24),
# and camera_config.py's WHITE_LED_FRONT_PIN (23) exactly — focus_tune.py is
# standalone, so it must drive the LED itself; nothing else will turn it on.
LED_PIN = {"rear_ir": 27, "front_visible": 24, "white_front": 23}[MODE]
_gpio_chip = "/dev/gpiochip0"
_led_request = None
try:
    import gpiod
    from gpiod.line import Value, Direction
except Exception as e:
    gpiod = None
    print(f"[focus_tune] gpiod import failed ({e}) — LED will NOT be turned "
          f"on; sharpness will read ~0.0 the whole time.", flush=True)


def led_on(on: bool):
    global _led_request
    if gpiod is None:
        return
    if _led_request is None:
        _led_request = gpiod.request_lines(
            _gpio_chip,
            consumer="focus_tune",
            config={LED_PIN: gpiod.LineSettings(
                direction=Direction.OUTPUT, output_value=Value.INACTIVE)},
        )
    _led_request.set_value(LED_PIN, Value.ACTIVE if on else Value.INACTIVE)


# Starting manual exposure/gain for front_visible mode. This camera's
# driver rejects auto_exposure=3 ("aperture priority" / full auto) outright
# — v4l2-ctl returns a hard error, not a soft fallback — so we can't rely on
# AE at all here and must pick manual values instead. These are just a
# starting guess for ordinary room/desk lighting; EDIT THEM if the startup
# frame check below still shows a very dark (or blown-out) frame.
FRONT_VISIBLE_EXPOSURE_US = 30000
FRONT_VISIBLE_GAIN = 300  # Arducam scale, 100-2200

# Starting manual exposure/gain for white_front mode. The front panel White
# LED strip is a much brighter, more direct illuminant than front_visible's
# green service LED, so it needs a shorter exposure / lower gain starting
# point rather than reusing FRONT_VISIBLE_EXPOSURE_US/GAIN above. EDIT THESE
# if the startup frame check below shows the image is too dark (raise
# exposure/gain) or blown out / all-white (lower them).
WHITE_FRONT_EXPOSURE_US = 8000
WHITE_FRONT_GAIN = 150  # Arducam scale, 100-2200

WINDOW_NAME = "Siemens Star Focus"


def sharpness_score(gray: np.ndarray) -> float:
    """Variance of the Laplacian, computed directly on the raw grayscale
    ROI — higher means sharper. Exposure and gain are locked to fixed
    manual values before the sweep starts (apply_ir_transmission_preset()
    for rear_ir, or the forced manual exposure/gain for front_visible /
    white_front), so frame-to-frame brightness is already consistent under
    fixed illumination. No per-frame renormalization is needed to remove a
    brightness confound here, and — critically — doing one anyway actively
    breaks this metric under defocus.

    A previous version of this function stretched each frame's own
    min/max pixel range to a fixed 0-1 span before scoring, intending to
    stop a brighter/higher-contrast frame from outscoring a genuinely
    sharper one. But a Siemens star's black/white spokes blur together
    toward flat mid-gray as focus is lost, so the frame's true (max-min)
    range SHRINKS the further out of focus you go. Rescaling that shrunken
    range back up to a fixed span amplifies whatever is left in it — by
    that point mostly sensor read noise, not real edge detail — so the
    reported "sharpness" could climb even as the lens moved further from
    correct focus. That is the "score keeps increasing past 200 while the
    image is visibly more blurred" failure. Scoring the raw grayscale
    directly (no rescaling) removes that noise-amplification path; with
    exposure/gain already fixed, relative comparisons across the sweep
    remain valid.
    """
    lap = cv2.Laplacian(gray.astype(np.float64), cv2.CV_64F)
    return float(lap.var())


def main():
    # Open at FULL resolution rather than the downsampled preview stream.
    # Fine focus differences get smoothed away at preview (1280x960)
    # resolution, so the score is far more sensitive to small ring
    # adjustments when measured at the full 5120x3840 capture size.
    settings = cam.load_settings()
    fw = int(settings.get("Arducam_FullWidth", 5120))
    fh = int(settings.get("Arducam_FullHeight", 3840))
    cam._open_capture(fw, fh)

    if MODE == "rear_ir":
        # Lock exposure/gain to your saved Rear IR values so brightness
        # changes don't masquerade as focus changes while turning the ring.
        # Only valid under the actual Rear IR panel's brightness.
        live = cam.apply_ir_transmission_preset(None)
        cam.apply_settings(live)
    elif MODE == "front_visible":
        # front_visible: this camera's driver rejects true auto-exposure
        # (auto_exposure=3 fails outright — confirmed on real hardware), so
        # force manual mode (value=1, known to work) with a starting
        # exposure/gain for ordinary lighting instead of the Rear-IR-tuned
        # values, which are wrong for this much dimmer light source.
        cam._set_auto_exposure(False)
        cam._v4l2_set("exposure", cam._us_to_v4l2_exposure(FRONT_VISIBLE_EXPOSURE_US))
        cam._v4l2_set("gain", FRONT_VISIBLE_GAIN)
        print(f"Manual exposure/gain forced for front_visible mode: "
              f"{FRONT_VISIBLE_EXPOSURE_US}us / gain {FRONT_VISIBLE_GAIN} "
              f"— edit the FRONT_VISIBLE_EXPOSURE_US / FRONT_VISIBLE_GAIN "
              f"constants near the top of this script if the frame below "
              f"is still too dark or too bright.")
        print("NOTE: the green LED (GPIO24) is a deliberately dim service "
              "light, not a photographic illuminant — for this test, "
              "ordinary room/desk light is likely a better light source.")
    else:  # white_front
        # Same reasoning as front_visible: this camera has no usable
        # auto-exposure, so force manual mode with a starting point tuned
        # for the much brighter white LED strip.
        cam._set_auto_exposure(False)
        cam._v4l2_set("exposure", cam._us_to_v4l2_exposure(WHITE_FRONT_EXPOSURE_US))
        cam._v4l2_set("gain", WHITE_FRONT_GAIN)
        print(f"Manual exposure/gain forced for white_front mode: "
              f"{WHITE_FRONT_EXPOSURE_US}us / gain {WHITE_FRONT_GAIN} "
              f"— edit the WHITE_FRONT_EXPOSURE_US / WHITE_FRONT_GAIN "
              f"constants near the top of this script if the frame below "
              f"is still too dark or too bright.")

    # Turn the illumination ON — see led_on() above.
    led_on(True)
    time.sleep(0.3)

    # Sanity-check that we're actually getting a non-black frame before
    # relying on the sharpness score at all. A flat/near-zero mean here
    # means the LED isn't lit, the target isn't in the frame, or exposure
    # is too low — sharpness will read ~0.0 regardless of focus until this
    # is fixed, so check it first rather than sweeping the lens blind.
    frame = cam._read_raw_frame()
    if frame is not None:
        gray0 = cam._to_gray(frame)
        print(f"Startup frame check — mean: {gray0.mean():.1f}  "
              f"min: {gray0.min()}  max: {gray0.max()}  (8-bit, 0-255)")
        if gray0.max() < 10:
            print("WARNING: frame looks essentially all-black. Check that "
                  "the LED for this mode is actually lit, the target is in "
                  "frame, and exposure/gain aren't set too low.\n")
    else:
        print("WARNING: could not read a startup frame at all.\n")

    # Try to open a live preview window. This needs a real display — it
    # will fail (harmlessly) over a plain SSH session with no X forwarding,
    # in which case we fall back to the original once-a-second
    # focus_debug_snapshot.jpg behavior so the script still works headless.
    live_window = False
    try:
        cv2.namedWindow(WINDOW_NAME, cv2.WINDOW_NORMAL)
        cv2.resizeWindow(WINDOW_NAME, 900, 675)
        live_window = True
        print(f"Live preview window opened ('{WINDOW_NAME}') — watch it "
              f"while turning the focus ring. Click the window and press "
              f"'q' or Esc to stop (or Ctrl+C in this terminal).\n")
    except Exception as e:
        print(f"[focus_tune] Could not open a live preview window ({e}) — "
              f"falling back to focus_debug_snapshot.jpg only. Run this "
              f"from a terminal on the Pi's own desktop (not plain SSH) to "
              f"get the live window.\n")

    print(f"Streaming at {fw}x{fh}. Point the camera at the Siemens star "
          f"target at your real working distance, then turn the focus ring "
          f"slowly. Ctrl+C to stop.\n")
    if not live_window:
        print("Writing focus_debug_snapshot.jpg once a second — the full "
              "frame, downsized, with a box around the region actually "
              "being scored. Pull it off the Pi (or open it in a file "
              "manager) to confirm the target is really inside that box "
              "before trusting the numbers below — a low, noisy score "
              "usually means it isn't.\n")

    best = 0.0
    best_time = time.time()
    last_snapshot = 0.0
    try:
        while True:
            frame = cam._read_raw_frame()
            if frame is None:
                print("no frame — retrying...                              ",
                      end="\r", flush=True)
                time.sleep(0.2)
                continue
            gray = cam._to_gray(frame)
            # Center crop — deliberately large (70% of the frame) rather
            # than a tight crop on the star's exact center. A Siemens
            # star's spokes get infinitely thin approaching the center, so
            # there's always a small soft "convergence blur" right at the
            # middle even at perfect focus — that's geometry, not defocus.
            # A tight crop centered on that point was mostly measuring that
            # one always-soft spot rather than the genuinely sharp spokes
            # around it, which is why scores stayed small no matter what
            # changed. This wider crop captures far more of the crisp outer
            # detail, which now dominates the score instead.
            h, w = gray.shape[:2]
            y0, y1 = int(h * 0.15), int(h * 0.85)
            x0, x1 = int(w * 0.15), int(w * 0.85)
            roi = gray[y0:y1, x0:x1]
            score = sharpness_score(roi)
            if score > best:
                best = score
                best_time = time.time()
            since_peak = time.time() - best_time
            bar_len = 50
            filled = min(bar_len, int((score / best) * bar_len)) if best > 0 else 0
            bar = "#" * filled + "-" * (bar_len - filled)
            print(f"sharpness: {score:9.2f}  |  peak: {best:9.2f} "
                  f"({since_peak:4.1f}s ago)  |  {bar}",
                  end="\r", flush=True)

            now = time.time()
            # Build the annotated preview every frame if the live window is
            # open (so the video looks smooth), otherwise only once a
            # second for the snapshot-file fallback.
            build_preview = live_window or (now - last_snapshot > 1.0)
            if build_preview:
                preview = cv2.resize(gray, (w // 4, h // 4))
                pr0, pc0 = y0 // 4, x0 // 4
                pr1, pc1 = y1 // 4, x1 // 4
                preview_bgr = cv2.cvtColor(preview, cv2.COLOR_GRAY2BGR)
                cv2.rectangle(preview_bgr, (pc0, pr0), (pc1, pr1), (0, 0, 255), 2)
                cv2.putText(preview_bgr, f"score: {score:.2f}   peak: {best:.2f}",
                            (10, 30), cv2.FONT_HERSHEY_SIMPLEX, 0.8, (0, 0, 255), 2)
                cv2.putText(preview_bgr, f"mode: {MODE}   ({since_peak:.1f}s since peak)",
                            (10, 60), cv2.FONT_HERSHEY_SIMPLEX, 0.6, (0, 255, 255), 2)
                # Live bar graph across the bottom of the frame, filled
                # proportional to score/peak — gives an at-a-glance visual
                # cue in the window itself, not just in the terminal.
                ph, pw = preview_bgr.shape[:2]
                bar_y0, bar_y1 = ph - 20, ph - 8
                cv2.rectangle(preview_bgr, (10, bar_y0), (pw - 10, bar_y1), (80, 80, 80), 1)
                if best > 0:
                    fill_w = int((pw - 22) * min(1.0, score / best))
                    cv2.rectangle(preview_bgr, (11, bar_y0 + 1),
                                  (11 + fill_w, bar_y1 - 1), (0, 200, 0), -1)

                if live_window:
                    cv2.imshow(WINDOW_NAME, preview_bgr)
                    key = cv2.waitKey(1) & 0xFF
                    if key == ord('q') or key == 27:  # 'q' or Esc
                        raise KeyboardInterrupt
                if now - last_snapshot > 1.0:
                    last_snapshot = now
                    cv2.imwrite("focus_debug_snapshot.jpg", preview_bgr)

            time.sleep(0.05 if live_window else 0.1)
    except KeyboardInterrupt:
        print(f"\n\nStopped. Best sharpness seen this session: {best:.2f}")
        print("If that peak was more than a few seconds before you stopped, "
              "turn back to that ring position before locking it down.")
    finally:
        led_on(False)
        if _led_request is not None:
            try:
                _led_request.release()
            except Exception:
                pass
        if live_window:
            try:
                cv2.destroyWindow(WINDOW_NAME)
            except Exception:
                pass
        cam.stop_camera()


if __name__ == "__main__":
    main()

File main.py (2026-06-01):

# ═══════════════════════════════════════════════════════════════════════════════
# SEEDLING IMAGER CONTROLLER — UNIVERSAL VERSION  v1.0.0
# Auto-scales GUI: 800×480 original display (s=1.0) ↔ 1280×720 Display2 (s=1.6)
# Features: dual 940 nm IR illumination, manual focus (need to adjust ref~7.589 D), tabbed Camera
# Config, AE stability gate, GT2 belt drive with dynamic bracket homing,
# per-mode camera presets, fixed experiment preview snapshot timing.
# ═══════════════════════════════════════════════════════════════════════════════
 
# main.py
import sys
from PySide6.QtWidgets import QApplication
from gui import SeedlingImagerGUI
 
def start_gui():
    app = QApplication(sys.argv)
    window = SeedlingImagerGUI()
    window.showFullScreen()  # dedicated touchscreen kiosk-style fullscreen (changed from window.show())
    sys.exit(app.exec())
 
if __name__ == "__main__":
    start_gui()

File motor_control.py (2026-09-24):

# motor_control.py — dynamic bracket midpoint centering, all 6 plates
#
# ═══════════════════════════════════════════════════════════════════════════════
# HARDWARE CONFIGURATION
# ═══════════════════════════════════════════════════════════════════════════════
#  Microstepping : 1/32  →  BTT TMC2209: MS2=GND, MS1=VCC_IO (3.3 V)
#  Drive ratio   : 3:1 belt  (NEMA 17 → carousel)
#  Steps per 60° : 200 full-steps × 32 microsteps × 3 (belt) / 6 plates = 3200
#  Optical stripe: 5 mm wide white PETG insert; expected W ≈ 192 µsteps
#  Hall sensor   : between plate positions 4 and 5 (active LOW, SWITCH_PIN=26)
#
# ═══════════════════════════════════════════════════════════════════════════════
# ⚠  IMPORTANT — BEFORE FIRST RUN AFTER HARDWARE CHANGE
# ═══════════════════════════════════════════════════════════════════════════════
#  Delete  motion_cal.json  if upgrading from a different microstepping setting.
#  Saved hall_to_leading / W values scale with step resolution; old values will
#  cause incorrect positioning at the new resolution.
# ═══════════════════════════════════════════════════════════════════════════════
#
# Flow:
#   1) Seek Hall sensor (pre-index, fast CW rotation)
#   2) CW to optical LOW (leading edge of Plate 1 stripe) → measure steps_to_leading
#   3) CW to optical HIGH (trailing edge) → measure initial W
#   4) Dynamic bracket (backlash-robust):
#        CW→HIGH (escape stripe if needed), CCW→LOW (trailing), CCW→HIGH (past
#        leading, measure W fresh), CW→LOW (re-validate leading), CW +round(W/2)
#   5) Persist W, hall→center to motion_cal.json
#   6) Each advance (plates 2-6): bracket-center on arriving stripe (fresh W)
#   7) Plate 1 wrap: same bracket with separate log prefix for clarity
#
# Public API (unchanged from v1.0):
#   driver_enable(), driver_disable(), step_motor(), home(), advance(),
#   goto_plate(), get_current_plate(), get_calibration(),
#   rehome_quick_via_hall(), rehome_full_from_hall()

import time
import json
from pathlib import Path
import gpiod
from gpiod.line import Direction, Value, Bias

# ─────────────────────────────────────────────────────────────────────────────
# GPIO pin assignments
# ─────────────────────────────────────────────────────────────────────────────
CHIP        = "/dev/gpiochip0"
EN_PIN      = 21
STEP_PIN    = 20
DIR_PIN     = 16
SWITCH_PIN  = 26   # Hall sensor     (active LOW)
OPTICAL_PIN = 22   # Reflective opt. (active LOW when stripe is under sensor) (moved from 19 081226: freed for FarRed germination LED)

# ─────────────────────────────────────────────────────────────────────────────
# Motion constants  —  1/32 microstepping
# ─────────────────────────────────────────────────────────────────────────────
# 200 full-steps/rev × 32 µsteps × 3:1 belt / 6 positions = 3200 µsteps per 60°
steps_per_60_deg = 3200

# Step pulse half-period (seconds).
# SLOW_DELAY = 1.0 ms  →  500 steps/s  →  ~6.4 s per 60° advance.
# FAST_DELAY = 0.5 ms  →  1000 steps/s  →  used for Hall seek & rapid moves.
SLOW_DELAY = 0.0010
FAST_DELAY = 0.0005

# Hall seek batch size — number of steps per polling iteration.
# 40 steps × 1 ms/step = 40 ms/batch.  At 19 200 steps/rev this gives ~19 s
# worst-case seek (Hall just behind current position), comfortably within the
# 20 s timeout below.  Scale this if FAST_DELAY is changed.
HALL_STEP_BATCH = 40

# ─────────────────────────────────────────────────────────────────────────────
# Centering options
# ─────────────────────────────────────────────────────────────────────────────
DIR_INVERT = True   # True for belt drive;  False for gear/direct drive

# Dynamic bracket backoff fraction.
# 0.0 = land exactly at geometric center of stripe (recommended).
# Small positive value (e.g. 0.05) shifts landing slightly CCW of center.
CENTER_BACKOFF_FRAC = 0.0

# Optional CW trim after backoff.  Keep 0 — avoids double-applying CW after
# the backoff step.  Increase only if you observe a consistent CW bias.
FINE_CENTER_TRIM = 0

# ─────────────────────────────────────────────────────────────────────────────
# Optical window (W) validity bounds  —  5 mm stripe @ 1/32 µstepping
# ─────────────────────────────────────────────────────────────────────────────
# Geometry:  R_trigger ≈ 80 mm, circumference ≈ 502 mm
#            steps/mm @ 1/32 = 19 200 steps/rev / 502 mm = 38.2 steps/mm
#            5 mm stripe → W ≈ 5 × 38.2 = 191 ≈ 192 steps
#
# W_MIN_VALID  : below this → stripe too narrow / sensor misaligned / wrong pin
# W_MAX_VALID  : above this → spurious read (two stripes merged, wrong pin, etc.)
# W_FALLBACK   : substituted only when measurement falls outside valid range
#                (triggers a logged warning; investigate before relying on it)
W_MIN_VALID =  80
W_MAX_VALID = 350
W_FALLBACK  = 192

# ─────────────────────────────────────────────────────────────────────────────
# Seek distance limits (µsteps)  —  all scaled ×4 vs 1/8 microstepping
# ─────────────────────────────────────────────────────────────────────────────
# _FULL_SPAN   : default limit for inter-plate seeks (CW/CCW to stripe edge).
#                2 × 60° = 120° of carousel travel — safely finds any edge
#                within one plate-spacing even if the advance overshot.
_FULL_SPAN  = steps_per_60_deg * 2   # 6400 µsteps

# _HALL_LEAD   : maximum steps from Hall trigger to Plate 1 leading edge.
#                Set equal to _FULL_SPAN (120°) which is generous.
_HALL_LEAD  = steps_per_60_deg * 2   # 6400 µsteps

# _W_SEEK_LIM  : limit for the CCW→HIGH seek that measures stripe width (W).
#                Must be > W_MAX_VALID.  800 >> 350, giving 2× headroom.
_W_SEEK_LIM = 800                    # µsteps

# ─────────────────────────────────────────────────────────────────────────────
# Calibration persistence
# ─────────────────────────────────────────────────────────────────────────────
CAL_PATH = Path("motion_cal.json")
_cal = {
    "opt_window_width":        None,   # W  (µsteps) — last measured stripe width
    "opt_center_from_leading": None,   # C = W // 2  (geometric midpoint offset)
    "hall_to_leading":         None,   # µsteps: Hall trigger → Plate 1 leading edge
    "hall_to_center":          None,   # µsteps: Hall trigger → Plate 1 center
}

current_plate = 0   # 0 = unknown / not yet homed
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

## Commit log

2026-04-15 v0.07: dual IR illumination, tabbed Camera Config, fixed preview snapshot timing, GT2 belt homing
    [camera.py, camera_config.py, experiment_runner.py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]
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2026-06-17 Create README for Seedling Imager hardware design
    Added README.md for Seedling Imager hardware design, detailing assembly, components, and licensing.
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2026-06-24 Replace image placeholder with actual image link
    Updated image reference for Dual Bearing Belt Drive.
2026-06-24 Fusion 360 dual bearing belt drive subassembly components
    [dual bearing belt drive_drive plate.f3d, dual bearing belt drive_pulley spindle clamp.f3d]
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2026-08-21 Add OpenCV/V4L2 backend for Arducam 20MP camera
    This file implements an OpenCV/V4L2 backend for the Arducam 20MP AR2020 monochrome USB 3.0 camera, including settings persistence, device discovery, and frame capture functionality.
2026-08-21 Add Picamera2 backend for Raspberry Pi Camera
    Implement Picamera2 backend for Raspberry Pi Camera Module 3 with settings persistence and IR handling.
2026-08-21 Implement camera backend selection in UI
    Added a camera backend selector to the UI and updated settings handling.
2026-08-21 Implement camera backend dispatcher and settings management
    Refactor camera.py to implement backend dispatcher for camera selection and settings management.
2026-08-21 Refactor GPIO pin assignments and add germination LED controls
    Updated GPIO pin assignments for rear and front IR panels and added germination LED controls.
2026-08-21 Change OPTICAL_PIN from 19 to 22
    Updated OPTICAL_PIN to 22 to free pin 19 for LED.
2026-08-21 Update README for v1.2.0 features and changes
    Updated version to v1.2.0, added selectable camera backend and germination LEDs, reshuffled GPIO pins.
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2026-08-25 Update LED handling and illumination modes in gui.py
    Refactor LED control and update illumination logic in GUI.
2026-08-25 Implement DAYLIGHT and DARK growth modes for LEDs
    Add growth mode handling for germination LEDs in experiment runner.
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2026-08-26 Implement focus stability gate for manual focus
    Add focus stability gate to ensure lens settles at target position before capturing images.
    [experiment_runner.py]
2026-08-28 Implement confirmation dialog for ending experiments
    Added confirmation dialog before ending an experiment to prevent accidental termination and avoid GUI freezing.
    [gui.py]
2026-09-05 Validate camera settings and update documentation
    Updated camera_arducam_usb3.py to reflect validation against physical hardware and adjustments to exposure and gain settings. Improved comments and documentation for clarity.
2026-09-05 Enhance camera config with Arducam Rear IR gain
    Added Arducam-specific Rear IR gain settings and updated UI elements for camera configuration.
2026-09-05 Refactor pixmap scaling to maintain aspect ratio
    Updated the pixmap scaling method to preserve the true aspect ratio without cropping, preventing layout issues and ensuring the camera label's size remains stable.
    [gui.py]
2026-09-06 Change QSpinBox to QDoubleSpinBox for Rear IR settings
    Updated Rear IR settings to use QDoubleSpinBox for exposure and gain controls to fix rendering issues with QSpinBox.
    [camera_config.py]
2026-09-06 Style disabled tab text in camera_config.py
    Add explicit styling for disabled tab text in camera config
2026-09-06 Add focus_tune.py for live focus adjustment
    This script provides a quantitative live focus assistant for the Arducam AR2020 ACHF080402320MP lens, calculating a sharpness score based on the variance of the Laplacian method. It guides users in a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
2026-09-10 Implement Rear IR illumination control in focus_tune.py
    Added functionality to control Rear IR illumination for improved frame quality during focus tuning.
2026-09-10 Add front_visible mode and improve usage instructions
    Updated focus_tune.py to support front_visible mode for testing with different illumination. Enhanced LED control and clarified usage instructions.
2026-09-11 Fix GPIO pin and enhance sharpness_score documentation
    Updated GPIO pin for LED_GREEN_PIN and improved sharpness_score function documentation with contrast normalization details.
    [focus_tune.py]
2026-09-11 Preserve exposure and gain settings during capture
    Capture current exposure and gain settings before reopening the camera device to prevent unwanted auto-exposure adjustments.
    [camera_arducam_usb3.py]
2026-09-11 Enhance frame capture reliability after mode switch
    Added verification after reapplying exposure and gain settings, and increased frame discard count to ensure fresh frames are captured.
2026-09-11 Adjust frame discard settings and add validation
    Reduced the number of discarded frames after mode switch and adjusted frame period timing. Added validation for frame content to handle potential blank or corrupt frames during USB3 transfer.
2026-09-11 Enhance comments for first Plate #1 warm-up logic
    Added detailed comments explaining the warm-up logic for the first Plate #1 of the run, including conditions for Arducam and Picamera2 behavior.
2026-09-11 Refactor frame capture logic and improve comments
    Refactor frame validation and reopening logic to ensure valid captures. Improve comments for clarity on exposure settings and frame handling.
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2026-09-11 Add Arducam Live View exposure and gain settings
    Added Arducam-only Live View exposure and gain settings for better control during previews. Updated UI elements to reflect these new settings and ensure they are applied correctly.
    [camera_config.py]
2026-09-12 Refactor camera config layout and disable Arducam settings
    Updated the layout of camera configuration options to use labels for better clarity. Disabled general settings for Arducam backend to prevent misleading options.
    [camera_config.py]
2026-09-12 Refine IR grayscale image storage estimates
    Updated storage estimate constants for IR grayscale images based on camera backend. Adjusted image size calculation to be backend-specific.
2026-09-12 Add background worker for applying camera settings
    Introduced a background worker to handle camera settings application without freezing the GUI. This change improves responsiveness during potentially long-running operations.
2026-09-12 Implement background camera call worker and guards
    Add a background worker for camera calls to prevent GUI freezing during long operations. Implement guarded execution for camera settings and live view adjustments.
    [gui.py]
2026-09-12 Refactor Rear IR live view settings and control parsing
    Refactor live view settings for Rear IR exposure and gain to ensure correct application after captures. Improve handling of exposure_auto control parsing to prevent errors and maintain consistent settings.
    [camera_arducam_usb3.py]
2026-09-12 Merge settings on apply to prevent overwriting keys
    Merge new settings with existing on-disk settings to prevent overwriting other persisted keys. This change addresses a bug related to auto-exposure settings being reset on apply.
    [camera_config.py]
2026-09-12 Improve comments on exposure/gain restoration logic
    Refactor comments for clarity and correctness regarding exposure/gain handling during image capture.
    [camera_arducam_usb3.py]
2026-09-12 Improve snapshot handling for camera exposure/gain
    Enhance snapshot functionality to ensure correct exposure/gain settings are restored after displaying a low-res frame. This prevents interference with subsequent plate captures.
    [gui.py]
2026-09-12 Disable automatic exposure for Arducam sensor
    Disable automatic exposure due to poor performance on specific hardware. Updated comments to clarify the reasoning behind the change.
2026-09-12 Refactor camera settings application in run method
    Updated camera settings application logic to use IR Live View preset instead of default settings. Added detailed comments explaining the changes and their implications.
2026-09-12 Revert to read-only frame grab for snapshot display
    Reverted to a read-only frame grab for snapshot display to avoid concurrency issues with camera control. Removed exposure/gain adjustments to prevent conflicts with ExperimentRunner's thread.
    [gui.py]
2026-09-12 Refactor show_experiment_snapshot for thread safety
    Updated the show_experiment_snapshot method to accept a frame argument instead of calling the camera directly. This change improves thread safety by avoiding concurrent camera access during experiments.
    [gui.py]
2026-09-12 Remove focus stability gate logic
    Removed manual focus stability gate logic and related comments from the experiment runner.
    [experiment_runner.py]
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2026-09-13 Implement frame discard after exposure/gain changes
    Added frame discard logic after exposure/gain adjustments to prevent blank/overexposed frames.
    [experiment_runner.py]
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2026-09-13 Set internal buffer size to 1 frame for fresh reads
    Added a property to set the internal buffer size to 1 frame to ensure the latest frame is read, preventing stale frame issues.
    [camera_arducam_usb3.py]
2026-09-13 Implement fresh stream check for camera snapshots
    Added a flag to track if the camera stream is fresh for snapshots, preventing stale frames from being used. Updated snapshot logic to check this flag before capturing frames.
    [experiment_runner.py]
2026-09-13 Refine snapshot handling and logging for skipped plates
    Updated logging and snapshot handling for skipped plates to improve clarity for non-technical users.
    [experiment_runner.py]
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2026-09-13 Improve snapshot reliability for camera captures
    Refactor camera snapshot handling to ensure fresh frames are captured for all plates, including those that are skipped, by using mock_capture for unselected plates.
    [experiment_runner.py]
2026-09-23 Fix Rear IR live-view overexposure and QThread crash on toggle
    - camera_picamera2.py: start_camera() now applies the Rear IR live-view
    preset at launch instead of leaving picamera2/libcamera hardware AE
    defaults active until the user manually hit Apply.
    - gui.py: removed the unconditional live-view brightness boost
    (enable_liveview_boost_for_ir) from set_live_view(), which was
    overriding the correct Rear IR manual exposure profile with a forced
    AE-on/bright-floor profile for the entire live view session -- this
    was the actual root cause of persistent overexposure.
    - gui.py: fixed QThread destroyed-while-running crash in
    _run_camera_call_guarded() by moving worker cleanup to QTh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
    [camera_picamera2.py, gui.py]
2026-09-23 Simplify Camera Config General tab to just the backend selector
    Removed AE/Exposure/Gain/AWB/Contrast/Brightness/Saturation/Sharpness/
    NoiseReduction/HDR widgets -- confirmed dead for both backends. Rear IR
    is the sole imaging mode and apply_ir_transmission_preset() always
    overrides every one of these fields before any capture or live view
    frame for Picamera2, and the Arducam backend's apply_settings() never
    reads these plain-named keys at all (the dialog already grayed them
    out for Arducam with that exact explanation). Tab renamed 'Camera
    Backend' since that's now its only control.
    [camera_config.py]
2026-09-23 Fix spelling of 'centered' in status messages
    [motor_control.py]
2026-09-24 Fix SETTINGS_PATH to resolve directory issues
    Updated SETTINGS_PATH to be anchored to the file's directory to fix issues with autostart behavior.
    [camera_config.py]
2026-09-24 Fix SETTINGS_PATH to use file's directory
    Update SETTINGS_PATH to be relative to the file's directory.
    [camera_picamera2.py]
2026-09-24 Fix SETTINGS_PATH to anchor to script directory
    Update SETTINGS_PATH to use the script's directory.
    [camera_arducam_usb3.py]
2026-09-24 Fix _SETTINGS_PATH to resolve correctly
    Update _SETTINGS_PATH to use the file's directory.
    [camera.py]
2026-09-24 Implement final manual-focus verification process
    Added final manual-focus verification after AE stability gate to ensure accurate focus before capture.
    [experiment_runner.py]
2026-09-24 Implement re-entrancy guards for dialog functions
    Added re-entrancy guards to daylight and dark mode dialog functions to prevent multiple invocations during laggy sessions.
    [experiment_setup.py]
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2026-09-24 Prevent AttributeError in timer button initialization
    Add guard clause to prevent AttributeError during initialization.
    [experiment_setup.py]
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2026-09-24 Implement focus/AE baseline pass at experiment start
    Added a one-time focus/AE baseline pass for improved stability during experiments, ensuring proper settling time before image capture.
    [experiment_runner.py]
2026-09-24 Refactor focus convergence and manual focus handling
    Updated max_wait_s parameter in _wait_for_focus_convergence function and removed nudge workaround in set_manual_focus function.
    [camera_picamera2.py]
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2026-09-24 Fix spelling of 'center' in comments and logs
    [motor_control.py]
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2026-09-24 Fix indentation for status_callback check
    [motor_control.py]
2026-09-24 Fix indentation in status callback for plate movement
    [motor_control.py]
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2026-09-25 Fix focus_tune.py: remove per-frame min/max normalization in sharpness_score()
    Per-frame contrast stretching amplified sensor noise as defocus shrank
    the frame's true dynamic range, causing the sharpness score to climb
    past 200 even as the image visibly worsened. Scoring raw grayscale
    directly is correct here since exposure/gain are already locked to
    fixed manual values before the sweep starts.
    [focus_tune.py]
2026-09-25 Add delay comments for camera release handling
    Added comments explaining the need for a delay when releasing and reopening the camera to prevent unresponsiveness.
    [camera_arducam_usb3.py]
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2026-10-04 Add seedling imager hardware: CAD (STEP), KiCad boards, BOM, render, licenses
    [100mm x 15 mm square petri dish magnetic fastener_8mm magnet.step, 2020 T-Slot cover_wire guide.step, 2020 T-slot End Cap with cover.step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]
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2026-10-26 GUI: remove border around message log; make all left-column button rows the same width
    The Home/Advance row was (button_width//2 - 5) x 2 plus row spacing, i.e.
    6 px wider than the other buttons on the 1280 px touchscreen and 14 px on a
    1920 px monitor. The Setup/Germination LED rows could also come up 1-2 px
    short from integer rounding. Each row now sums to exactly button_width.
    Newer Raspberry Pi OS / Qt6 images draw the default QTextEdit frame as a
    light border on the dark theme; set NoFrame + border:none on the log panel.
    Claude-Session: https://claude.ai/code/session_01GzQSkcMSDj4AJEZ4ve3aXi
2026-10-26 Installer: make the system journal persistent (override Raspberry Pi OS volatile default)
    Creating /var/log/journal alone did not take effect on the new System 1:
    logs were still lost at reboot. Write a journald drop-in with
    Storage=persistent and restart journald.
    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
2026-10-26 Camera stall handling: background Live View frames + automatic Arducam reconnect
    On the new System 1 the Arducam stopped streaming (no kernel-level USB
    error) right after a USB flash drive was hot-plugged. get_frame() ran on
    the GUI thread, so each read blocked for OpenCV's 10 s V4L2 timeout, the
    screen froze, and queued taps on Home were replayed as start/stop pairs.
    - gui.py: Live View frames come from a _LiveFrameWorker QThread; the GUI
    only receives finished frames and shows stall/reconnect status.
    - camera_arducam_usb3.py: 4 s read timeout, consecutive-failure count,
    recover_camera() (release, re-detect device, reopen, re-apply settings),
    triggered from get_frame() after 2 failed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
2026-10-26 Arducam reconnect: keep retrying until the camera is back on the bus
    Hardware test on System 1 (USB cable unplugged ~5 s): the first reconnect
    ran while the camera was still absent, failed, and none followed, because
    reads on a closed stream weren't counted as failures. The camera had
    already re-appeared at /dev/video0.
    - Count reads on a closed stream as failures, so retries continue.
    - recover_camera() first checks the camera is on the bus by sysfs name
    (never falls back to /dev/video0, which may be another node); if absent
    it leaves the stream closed and retries.
    - Retry interval 30 s -> 10 s; success now requires an actual frame.
    Tested: simulated unplug/replug (including return on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
2026-11-06 Rename the website to SeedlingAnalyzer
    The site now lives in the seedling imager monorepo, so the old
    ArabidopsisAnalysisV2 name no longer fits. Updates the site title, nav,
    landing page title and footer, the install guide intro, and the usage
    guide heading.
2026-11-06 Document the Save Timelapse button and cropped-image timelapse videos
    The viewer's Save Timelapse button and the cropped_timelapse videos written
    when Save Cropped Images is ticked were missing from the Single Plant
    Analysis page. The old text said cropped images were only 'required for'
    timelapse videos, which no longer describes what the app does.
2026-11-09 Fix convex hull results glob for the layout without an RPI folder
    '*/*/*/Results*' matched nothing now that results sit at
    <exp>/cam_X/plant_N/Results_k, so atlas generation found no data.

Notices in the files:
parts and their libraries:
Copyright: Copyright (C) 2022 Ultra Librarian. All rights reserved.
